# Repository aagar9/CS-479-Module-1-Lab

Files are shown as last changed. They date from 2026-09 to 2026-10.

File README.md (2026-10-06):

# CS 479 – Group 6

This repository is the master repository for **Group 6** in **CS 479 – Wearable Technology Laboratory**.

It will contain the code, documentation, hardware files, and other materials developed for each lab throughout the course.

## Repository Structure

Each lab is organized into its own folder:

- `lab1/` – Lab 1 files and documentation
- `lab2/` – Lab 2 files and documentation

Additional lab folders will be added as the course progresses.

## Group

**Group 6**

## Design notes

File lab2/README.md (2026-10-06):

# BME/CS 479 – Lab 2

## Heart Rate and Breathing Rate Wearable

## Overview

The goal of Lab 2 is to develop a wearable chest strap capable of monitoring a user's heart rate and respiratory rate.

The system uses an AD8232 heart monitor to collect an ECG signal and a Force Sensitive Resistor (FSR) to measure changes associated with inhalation and exhalation.

The collected signals will be processed and displayed through a Processing-based user interface.

---

## Hardware

The Lab 2 wearable uses:

- FireBeetle Board-328P with BLE 4.1
- Micro USB Interface Cable
- Rechargeable Lithium Battery
- FireBeetle Proto Board
- AD8232 Heart Monitor
- ECG Leads
- Snap-On ECG Electrodes
- Force Sensitive Resistor (FSR)
- 10 kOhm Resistor
- Elastic Band
- Tape or Glue
- 3D Printed FSR Backing
- 3D Printed Clasp
- Wire and Wire Wrapping Tool
- Solder and Soldering Iron
- Athletic Tape
- Female Headers

---

## System Design

The wearable collects two primary biosignals:

### ECG

The AD8232 heart monitor records the user's ECG signal.

The ECG signal will be used to calculate and display:

- Heart rate
- Resting heart rate
- Cardio zone
- ECG activity over time

### Respiration

The FSR detects changes caused by expansion and contraction of the chest during inhalation and exhalation.

The respiratory signal will be used to calculate and display:

- Respiratory rate
- Resting respiratory rate
- Inhalation duration
- Exhalation duration
- Respiratory activity over time

---

## User Interface

The user interface is being developed using **Processing (Java Mode)**.

The interface provides three primary operating modes:

1. Fitness Mode
2. Stress Monitoring Mode
3. Meditation Mode

The initial rough Processing UI prototype is located at:

`First_Heart_Breathing_UI/First_Heart_Breathing_UI.pde`

The initial UI currently uses simulated values and placeholder graphs. These will later be replaced with data collected from the wearable sensors.

---

## Fitness Mode

Fitness Mode will begin by collecting a **30-second baseline** from the user.

The baseline will be used to determine:

- Resting heart rate
- Resting respiratory rate

After baseline collection, the interface will display the user's current cardio zone.

Maximum heart rate will be estimated using:

`Maximum Heart Rate = 220 - age`

During physical activity, the interface will monitor the user's ECG and respiratory signals.

The interface will display:

- Current heart rate
- Current respiratory rate
- Cardio zone
- ECG activity
- Cardio-zone activity
- Respiratory activity
- Inhalation duration
- Exhalation duration

The activity graph will eventually be color-coded based on the amount of time spent in each cardio zone.

---

## Stress Monitoring Mode

Stress Monitoring Mode will also begin by collecting a **30-second baseline**.

The baseline will be used to determine:

- Resting heart rate
- Resting respiratory rate

The user's heart rate and respiratory rate will then be monitored during different activities.

The interface will compare the collected data with the user's baseline and use the input analysis to determine whether the user is:

- Calm
- Stressed

The final interface will automatically display the detected state.

---

## Meditation Mode

Meditation Mode will begin by collecting a **30-second baseline**.

The baseline will display:

- Resting heart rate
- Resting respiratory rate

During meditation, the interface will monitor:

- Current heart rate
- Current respiratory rate
- Inhalation duration
- Exhalation duration

The target breathing pattern is:

`Inhalation Period = 1/3 of Exhalation Period`

The interface will continually determine whether the user is maintaining this breathing pattern.

If the breathing criterion is not met for **three consecutive breaths**, an indicator will be activated on the interface.

---

## Required Interface Graphs

The final interface must display all three required graphs:

1. ECG
2. Cardio Zone
3. Respiratory Signal

The respiratory portion of the interface will also display:

- Respiratory rate
- Inhalation duration
- Exhalation duration

---

## Signal Processing

The ECG and respiratory signals may require signal processing to reduce noise and improve the accuracy of the calculated measurements.

Future development may include:

- Signal filtering
- Peak detection
- Heartbeat detection
- Breath detection
- Baseline calculation
- Heart-rate calculation
- Respiratory-rate calculation
- Inhalation and exhalation detection

---

## Current Progress

### Completed

- Repository reorganized into separate `lab1` and `lab2` folders
- Processing development environment configured
- Initial Processing UI created
- Fitness Mode button implemented
- Stress Monitoring Mode button implemented
- Meditation Mode button implemented
- Mode switching implemented
- Initial heart-rate display implemented using placeholder data
- Initial respiratory-rate display implemented using placeholder data
- Initial ECG graph implemented using simulated data
- Initial cardio-zone display implemented
- Initial respiratory graph implemented using simulated data
- Initial Stress Mode screen implemented
- Initial Meditation Mode screen implemented

### In Progress

- 30-second baseline collection
- FireBeetle integration
- AD8232 ECG sensor integration
- FSR respiratory sensor integration
- Live sensor communication with Processing
- ECG signal processing
- Heart-rate calculation
- Respiratory-rate calculation
- Inhalation and exhalation detection
- Cardio-zone calculation
- Cardio-zone activity graph
- Stress/calm classification
- Meditation breathing-pattern detection
- Three-consecutive-breath warning indicator

---

## Project Structure

```text
lab2/
├── README.md
└── First_Heart_Breathing_UI/
    └── First_Heart_Breathing_UI.pde

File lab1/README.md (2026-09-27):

# PPG Wearable – Fitness and Calm/Stress Monitoring

This repository contains the software developed for the PPG module of the Wearables and Nearables Technology Laboratory.

The project implements two main applications:

- **Task I – Fitness Mode**
- **Task II – Calm / Stress Detection**

An additional version of Task I also includes an **estimated calorie expenditure feature**.

---

## System Architecture

The wearable uses a peripheral/central BLE architecture:

MAX30101 / MAX32664  
→ Peripheral FireBeetle  
→ BLE  
→ Central FireBeetle  
→ USB / Serial  
→ Processing

The **peripheral FireBeetle** is connected to the PPG sensor and runs the Arduino firmware.

The **central FireBeetle** is connected to the computer and acts as a BLE-to-USB bridge.

The MAX32664 biometric hub performs the low-level PPG processing and provides already processed values such as:

- Heart rate
- SpO2
- Confidence
- Sensor status

The Processing applications therefore perform the higher-level logic, including signal validation, baseline acquisition, classification, graphing, and user-interface control.

---

# Repository Files

## `ppg1`

Processing application implementing **Task I – Fitness Mode**.

Before starting the task, the program checks whether the PPG signal has been reliably acquired using a rolling window containing the latest 10 HR samples.

A sample is considered valid when:

- `HR > 0`

The signal is accepted when:

- at least **7 of the latest 10 samples are valid**
- the most recent sample is also valid

After signal acquisition, a **30-second resting baseline** is recorded.

Resting HR is calculated as the mean of the valid HR samples acquired during this phase.

Signal quality is calculated as:

`valid samples / total received samples`

If baseline quality is below **70%**, the acquisition must be repeated.

### Fitness Mode

The estimated maximum heart rate is calculated as:

`HRmax = 220 - age`

Each valid HR measurement is expressed as a percentage of HRmax and assigned to the corresponding exercise-intensity zone.

The interface displays:

- Current HR
- Resting HR
- Average HR
- Beat interval
- SpO2
- Confidence
- Current cardio zone
- Activity time
- Classified time
- Signal quality
- Time spent in each cardio zone

The HR graph is color-coded according to the cardio zone.

When `HR = 0`, the sample is treated as missing data and is excluded from:

- HR averages
- cardio-zone classification
- zone-time accumulation
- graph points

This creates a graph gap instead of displaying an artificial HR value.

After pressing **STOP**, the complete session remains visible for review.

---

## `ppg_fitness_calories_no_age_limit`

Extended version of `ppg1`.

It implements the same **Fitness Mode**, while also estimating **energy expenditure and calories burned**.

The calorie calculation uses:

- Heart rate
- Age
- Sex
- Body mass

Energy expenditure is estimated from HR using sex-specific equations and is integrated over time.

Calorie integration is performed only during valid HR intervals.

If signal loss occurs, the integration is interrupted instead of estimating calories across missing data.

The interface additionally displays:

- Estimated calories

This feature is an additional project implementation and is not required for the basic Fitness Mode.

---

## `ppg2`

Processing application implementing **Task II – Calm / Stress Detection**.

The initial signal acquisition and 30-second resting baseline use the same logic as Task I.

The Task II workflow is:

Resting baseline  
→ Calm calibration  
→ Stress calibration  
→ Live detection

### Calm Calibration

During Calm calibration, HR is recorded while the user attempts to relax.

A **time-weighted mean HR** is calculated, giving slightly greater importance to the later samples of the calibration.

The calibration is accepted only if HR decreases by at least **1 bpm** relative to resting HR.

### Stress Calibration

During Stress calibration, HR is recorded while the user performs the stress task.

The Stress calibration must last at least **60 seconds**.

The same time-weighted averaging method is used.

The calibration is accepted only if HR increases by at least **1 bpm** relative to resting HR.

If a new calibration is too weak, the previously accepted calibration is retained.

### Live Detection

During live detection, the latest **10 HR samples** are stored in a rolling window.

If at least **7 of the 10 samples are valid**, a smoothed HR is calculated from the valid values.

The smoothed HR is compared with personalized Calm and Stress thresholds obtained from the calibration phase.

The possible detected states are:

- `CALM`
- `NEUTRAL`
- `STRESSED`

A **2-second persistence requirement** is used before confirming a state transition.

This prevents brief threshold crossings from being interpreted as real state changes.

The algorithm also uses **hysteresis**, with different entry and exit thresholds, to avoid repeated switching when HR oscillates near a decision boundary.

When a transition to `STRESSED` is confirmed, Processing sends the command:

`'B'`

to the wearable, which triggers two buzzer tones.

The Task II interface displays:

- Current HR
- Smoothed HR
- Resting HR
- Beat interval
- SpO2
- Confidence
- Calm threshold
- Stress threshold
- Current detected state
- Signal quality
- Detection time
- Measured and smoothed HR curves

---

# Arduino Firmware

## `arduino_sensor`

Arduino firmware used for **Task I**.

The peripheral FireBeetle communicates with the MAX32664 biometric hub and reads the processed biometric outputs.

The firmware transmits:

- Heart rate
- Confidence
- SpO2
- Status

The data flow is:

PPG sensor  
→ Peripheral FireBeetle  
→ BLE  
→ Central FireBeetle  
→ USB  
→ Processing

The Processing applications `ppg1` and `ppg_fitness_calories_no_age_limit` read these data and perform the application-level processing.

---

## `arduino_sensor_buzzer`

Arduino firmware used for **Task II**.

It performs the same sensor acquisition and transmission as `arduino_sensor`, but it also receives the buzzer command from Processing.

When the peripheral receives:

`'B'`

the buzzer produces two tones.

The feedback path is:

Processing detects `STRESSED`  
→ sends `'B'`  
→ Central FireBeetle  
→ BLE  
→ Peripheral FireBeetle  
→ buzzer sounds twice

---

# Processing Program Structure

The Processing applications use an event-driven structure.

## `setup()`

Runs once when the program starts.

It initializes:

- the graphical interface
- serial communication
- colors and layout variables
- program variables

## `draw()`

Runs continuously.

It is mainly responsible for:

- drawing the current interface screen
- updating graphical elements
- checking time-based transitions

Sensor sample counters are not updated inside `draw()`.

## `serialEvent()`

Runs whenever a complete sensor record is received.

It:

1. Reads the serial data.
2. Extracts HR, SpO2 and confidence.
3. Determines whether the HR sample is valid.
4. Records the sample time.
5. Sends the sample to the correct algorithm according to the current program state.

For example:

- `WAITING_SIGNAL` → update the 10-sample validity window
- `BASELINE` → process the resting-baseline sample
- `FITNESS_ACTIVE` → process the Fitness sample
- `CALM_ACTIVE / STRESS_ACTIVE` → process the calibration sample
- `DETECTION_ACTIVE` → update the live-detection algorithm

## `mousePressed()`

Runs only when the user clicks.

It handles actions such as:

- START
- STOP
- Retry
- Calm Calibration
- Stress Calibration
- Start Detection

---

# Data Quality Strategy

The software includes several checks to manage temporary PPG signal loss.

| Stage | Strategy |
|---|---|
| Initial acquisition | At least 7 valid samples among the latest 10 |
| Latest sample | Must also be valid |
| Resting baseline | 30-second acquisition |
| Baseline acceptance | At least 70% valid samples |
| Invalid HR | HR = 0 treated as missing data |
| Fitness graph | Missing samples shown as gaps |
| Task II | 10-sample rolling mean |
| State transition | 2-second persistence |
| State stability | Hysteresis with different entry/exit thresholds |

---

# Beat Interval

The beat interval displayed by the interface is estimated from the current HR as:

`Beat interval [ms] = 60000 / HR`

It is therefore an HR-derived estimate rather than a direct beat-to-beat measurement extracted from individual PPG peaks.

---

# How to Run

1. Pair the peripheral and central FireBeetle boards.
2. Upload the appropriate Arduino firmware to the peripheral board:
   - `arduino_sensor` for Task I
   - `arduino_sensor_buzzer` for Task II
3. Connect the central FireBeetle to the PC through USB.
4. Close the Arduino Serial Monitor.
5. Open the corresponding Processing application:
   - `ppg1`
   - `ppg_fitness_calories_no_age_limit`
   - `ppg2`
6. Select the correct serial port if necessary.
7. Position the PPG sensor correctly.
8. Wait for stable signal acquisition.
9. Follow the instructions shown in the Processing interface.

---

# File Summary

| File | Platform | Function |
|---|---|---|
| `ppg1` | Processing | Task I – Fitness Mode |
| `ppg_fitness_calories_no_age_limit` | Processing | Task I + calorie estimation |
| `ppg2` | Processing | Task II – Calm / Stress Detection |
| `arduino_sensor` | Arduino | PPG acquisition and transmission for Task I |
| `arduino_sensor_buzzer` | Arduino | PPG acquisition, transmission, and buzzer feedback for Task II |

---

## Notes

The MAX32664 performs the low-level PPG filtering and biometric processing.

The custom Processing software implements the application-level algorithms developed for this project, including:

- signal validation
- resting-HR estimation
- cardio-zone classification
- personalized Calm/Stress calibration
- temporal smoothing
- persistence
- hysteresis
- graphical visualization
- buzzer feedback

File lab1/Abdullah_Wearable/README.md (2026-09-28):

# Wearable PPG Monitor — BME/CS 479

Arduino firmware and a single-file Processing interface for the wearable heart-rate and blood-oxygen lab project.

## Files

- `WearableLabComplete/WearableLabComplete.pde`: Processing application. Open this file in Processing; keep its enclosing folder name unchanged.
- `WearableLabSensor/WearableLabSensor.ino`: firmware for the wearable FireBeetle carrying BOTH the PPG sensor and buzzer.

No separate Java source files, verification tools, recordings, or exported participant data are needed to run the application.

## Hardware and wiring

Two already-paired DFRobot FireBeetle 328P BLE 4.1 boards, a SparkFun MAX30101/MAX32664 sensor board, and a buzzer. This setup assumes the existing BLE pairing and transport configuration; these sketches do not establish pairing.

| Wearable FireBeetle | Sensor board |
| --- | --- |
| 3V3 | 3V3 |
| GND | GND |
| SDA | SDA |
| SCL | SCL |
| D4 | RST |
| D5 | MFIO |

Buzzer positive connects to D12; negative connects to GND. The USB-connected FireBeetle has no external sensor or buzzer.

## Run Processing

1. Install Processing 4 (developed with 4.5.6). Its desktop distribution includes a Java runtime; no separate Java installation is needed.
2. Ensure the Processing Serial library is available (`processing.serial`).
3. Copy the entire `WearableLabComplete` folder and open its `.pde` file.
4. Connect the empty bridge board by USB and power the paired wearable board.
5. Close Arduino Serial Monitor and other applications using the serial port.
6. Run the sketch and select the bridge's actual port on the setup screen. COM3 is only the original computer's default. Communication uses 115200 baud.
7. Check live readings and use Test buzzer. Enter the wearer's age and record a new resting baseline and calibrations.

If the boards already have the correct firmware, uploading Arduino code again is unnecessary.

## Upload Arduino firmware

Install Arduino IDE, the board support for your FireBeetle, and **SparkFun Bio Sensor Hub Library** through Library Manager. `Wire` comes with the Arduino core. Use the board configuration previously confirmed for the physical FireBeetle 328P, which runs at 3.3 V / 8 MHz.

1. Stop Processing and close Serial Monitor.
2. Disconnect/power off the computer-side FireBeetle. Connect the sensor-and-buzzer board directly by USB and upload `WearableLabSensor` to it.
3. Restore normal power and the existing paired wireless arrangement, then run Processing.

Keep only the intended target powered during the upload: the paired FireBeetle link supports wireless programming. The computer-side board is already configured and needs no sketch from this package.

## Application behavior

- Heart rate, oxygen saturation, confidence, and signal-quality display.
- 30-second resting baseline.
- Fitness mode with colored heart-rate zones, recovery graph, and time in each zone.
- Calm calibration lasting at least 30 seconds and stress calibration lasting 60 seconds.
- Monitoring uses smoothed heart rate and requires a sustained threshold crossing for 2 seconds before entering STRESSED. Entry triggers two beeps; it does not continuously repeat while remaining STRESSED.
- Test buzzer sends the same command path and displays board acknowledgments.
- Raw PPG pulse-interval detection; legacy heart-rate-only data uses a clearly labeled estimated interval.
- Optional CSV export. Generated exports are ignored by Git.

If calibration has sufficient valid data but does not produce the expected heart-rate change, the interface labels its fallback thresholds as defaults. Stress labels are heart-rate-based classifications, not confirmation of a person's emotional state.

## Signal failures and validation

Firmware checks sensor replies, rejects incomplete samples, and attempts sensor reinitialization after failures. Processing clears stale readings on sensor faults. Persistent FIFO errors still require checking sensor power and connections.

Before packaging, the source version was compiled for AVR ATmega328P 3.3 V / 8 MHz (Arduino AVR core 1.8.6), and the Processing version passed 36 behavior checks. This package preserves those source files unchanged. Physical fault recovery, long-duration BLE reliability, and operation on another computer have not been verified here.

Raw packets are limited to 25 per second. Pulse intervals therefore have roughly 40 ms sample spacing plus polling jitter; they are not ECG beat-interval measurements.

## Add to the shared GitHub repository

Copy the two sketch folders, this README, and `.gitignore` into the desired project directory of the shared repository. Preserve each sketch's folder and filename. If that repository already has a README or `.gitignore`, merge these contents rather than replacing the existing files.

Review and commit the files through your usual GitHub workflow. Do not upload the ZIP itself as a substitute for the source folders. No license is assigned by this package; the team can choose one if needed.

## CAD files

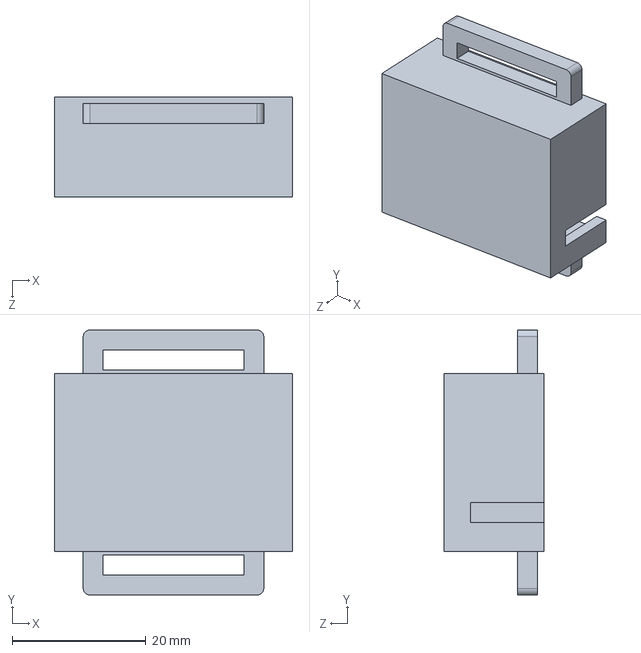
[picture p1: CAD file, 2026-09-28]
lab1/Abdullah_Wearable/PPG_Cover_Strap_v8.SLDPRT
35.6 x 39.6 x 15.0 mm

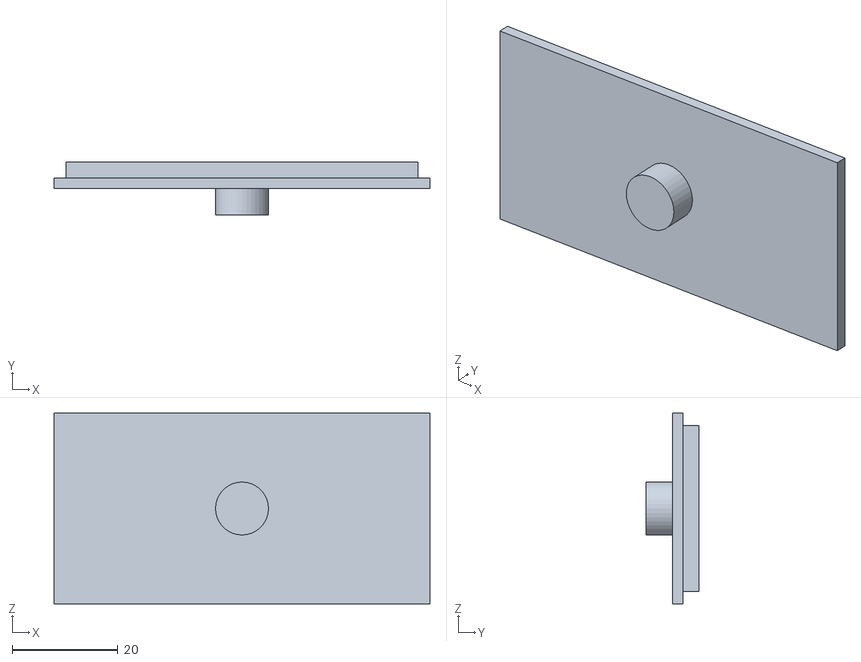
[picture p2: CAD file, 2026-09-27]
lab1/box_cap.STL
71.0 x 10.0 x 36.0

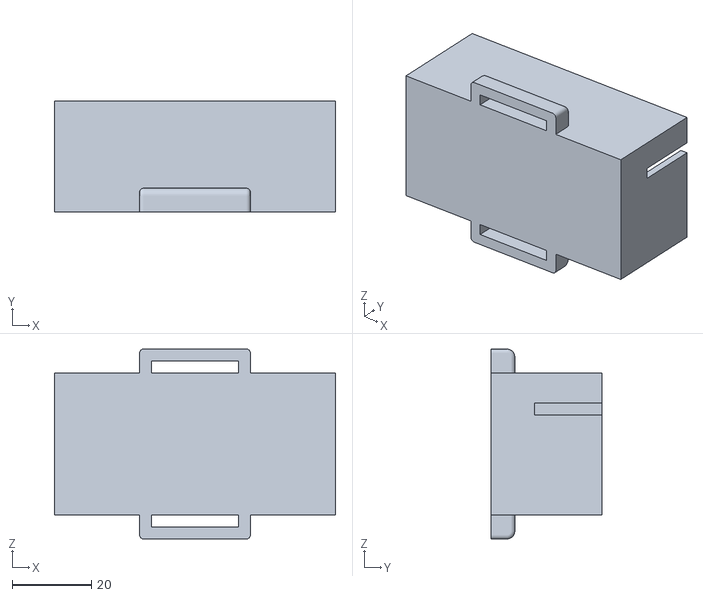
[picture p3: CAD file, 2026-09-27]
lab1/Box.STL
71.0 x 28.0 x 48.0

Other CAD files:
lab1/lid.SLDPRT
lab1/Abdullah_Wearable/PPG_Cover_Strap_v8.stl

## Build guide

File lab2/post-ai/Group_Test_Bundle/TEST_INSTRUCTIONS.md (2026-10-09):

# Group testing package (post-AI)

## Test these exact files

1. **Arduino IDE:** `Group_Test_Arduino/Group_Test_Arduino.ino`
2. **Processing IDE:** `Group_Test_Bundle/Group_Test_Bundle.pde`

The Processing sketch contains these original tabs, unchanged in logic:
- Heart_Breathing_Integrated.pde
- FitnessMode.pde
- MeditationMode.pde
- SignalProcessing.pde
- StressMode.pde

Firmware copied from: `lab2/pre-ai/First_Heart_Breathing_UI/arduino_Lab02.ino`

## Test order
1. Close Processing and the Arduino Serial Monitor before changing which app uses the serial port.
2. Upload the Arduino sketch to the FireBeetle using the correct board and port.
3. Open the single Processing `.pde` file. Confirm the serial port and baud rate match the board (the current UI may have a hardcoded `COM3`).
4. Verify live ECG and respiration data, HR/RR and inhale/exhale times.
5. Fitness: baseline, activity selection, all five animations (especially stairs), cardio zones, graphs, end/results.
6. Stress: all three 30-second calibration phases, monitoring status and graphs.
7. Meditation: baseline, 1:3 breathing target, alert after three consecutive missed breaths.
8. Test on Windows and macOS if available; record screenshots and Processing console errors.

**Important:** Combining files does not guarantee compilation or hardware compatibility. Test with the actual board. Do not open the original multi-tab sketch at the same time when checking this bundle.

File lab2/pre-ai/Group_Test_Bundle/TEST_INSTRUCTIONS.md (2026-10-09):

# Pre-AI group testing package

## Exact files to open
- **Processing:** `Pre_AI_Group_Test/Pre_AI_Group_Test.pde`
- **Arduino IDE:** `Pre_AI_Arduino/Pre_AI_Arduino.ino`

## Testing checklist
1. Select the correct FireBeetle board and port in Arduino IDE. Verify, then upload firmware.
2. Close Arduino Serial Monitor before starting Processing (only one app can own the port).
3. Open the Processing `.pde` and press Run. Confirm it compiles.
4. Confirm serial port connects and ECG and FSR graphs receive live samples.
5. Test ECG lead removal and reconnection; Arduino sends `!,FSR` when leads are off.
6. Test Home, Fitness, Stress and Meditation buttons and 30-second baseline behavior.
7. Record screenshots, actual HR/RR readings, and any compilation or serial errors.

## Notes
The Processing source is consolidated from the three existing pre-AI tabs.
The additional `Hearth_breathing_integrated.pde` is deliberately excluded because it is a separate overlapping sketch.
The firmware is copied from `arduino_Lab02.ino`.
The bundle is not hardware-validated by this script.

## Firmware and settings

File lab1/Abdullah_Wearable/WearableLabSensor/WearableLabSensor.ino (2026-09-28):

#include <Wire.h>
#include <SparkFun_Bio_Sensor_Hub_Library.h>

// FireBeetle 328P BLE 4.1: preserve the lab's wiring.
const uint8_t RESET_PIN=4, MFIO_PIN=5, BUZZER_PIN=12, HUB_ADDRESS=0x55;
SparkFun_Bio_Sensor_Hub bioHub(RESET_PIN, MFIO_PIN);
bool sensorReady=false;
uint8_t beepPhase=0;
unsigned long beepStarted=0, lastPoll=0;
uint8_t readFailureStage=0, readFailureCode=0;
unsigned long lastErrorReport=0;
bool errorReported=false;
unsigned long lastRecoveryAttempt=0, lastTransmit=0, lastGoodSample=0;
uint8_t recoveryAttempts=0, consecutiveCountErrors=0;
const unsigned long TRANSMIT_INTERVAL_MS=40; // At most 25 raw packets/s over BLE.

// Execute a hub read with explicit I2C/status/length checks. MODE_ONE sensor +
// algorithm output is 18 payload bytes, fitting the AVR Wire 32-byte buffer.
bool hubRead(uint8_t family,uint8_t index,uint8_t *data,uint8_t count) {
  readFailureStage=0; readFailureCode=0;
  Wire.beginTransmission(HUB_ADDRESS); Wire.write(family); Wire.write(index);
  uint8_t busResult=Wire.endTransmission();
  if(busResult!=0) { readFailureStage=1; readFailureCode=busResult; return false; }
  delay(2); // Required hub command response delay, not a sampling-rate delay.
  uint8_t got=Wire.requestFrom(HUB_ADDRESS,(uint8_t)(count+1));
  if(got!=count+1) {
    readFailureStage=2; readFailureCode=got;
    while(Wire.available()) Wire.read(); return false;
  }
  uint8_t status=Wire.read();
  for(uint8_t i=0;i<count;i++) data[i]=Wire.read();
  if(status!=0) { readFailureStage=3; readFailureCode=status; return false; }
  return true;
}

// Report the actual failure once per second instead of flooding the serial link.
// I2C write code 2 = address NACK; code 3 = data NACK. A nonzero hub status
// is a sensor command response, distinct from wiring/transport errors.
void reportReadError(bool fifoCount) {
  if(errorReported && millis()-lastErrorReport<1000) return;
  errorReported=true; lastErrorReport=millis();
  Serial.print(fifoCount?F("ERROR FIFO count | "):F("ERROR FIFO sample | "));
  if(readFailureStage==1) Serial.print(F("I2C write code="));
  else if(readFailureStage==2) Serial.print(F("short reply bytes="));
  else Serial.print(F("hub status="));
  Serial.println(readFailureCode);
}

// Decode the unsigned 24-bit optical channel values.
uint32_t value24(const uint8_t *p) { return ((uint32_t)p[0]<<16)|((uint32_t)p[1]<<8)|p[2]; }

// Start only one double-beep sequence at a time; do not block sensor polling.
void checkBuzzer() {
  while(Serial.available()) {
    char command=Serial.read();
    if(command=='B' && beepPhase==0) { beepPhase=1; beepStarted=millis(); tone(BUZZER_PIN,1800); Serial.println(F("BUZZER started")); }
  }
  unsigned long elapsed=millis()-beepStarted;
  if(beepPhase==1 && elapsed>=300) { noTone(BUZZER_PIN); beepPhase=2; beepStarted=millis(); }
  else if(beepPhase==2 && elapsed>=250) { tone(BUZZER_PIN,1800); beepPhase=3; beepStarted=millis(); }
  else if(beepPhase==3 && elapsed>=300) { noTone(BUZZER_PIN); beepPhase=0; Serial.println(F("BUZZER complete")); }
}

// Reinitialize both the I2C peripheral and the sensor after a broken FIFO read.
// Explicit pin arguments restore MFIO to OUTPUT before the reset sequence.
bool initializeSensor() {
  Wire.end(); Wire.begin(); Wire.setClock(100000);
  Wire.setWireTimeout(25000,true); // AVR Wire: bound a stuck bus and reset TWI on timeout.
  Wire.clearWireTimeoutFlag();
  if(bioHub.begin(Wire,RESET_PIN,MFIO_PIN)!=0) { Serial.println(F("ERROR sensor connection")); return false; }
  if(bioHub.configSensorBpm(MODE_ONE)!=0) { Serial.println(F("ERROR sensor configuration")); return false; }
  if(bioHub.agcAlgoControl(ENABLE)!=0) { Serial.println(F("ERROR automatic gain configuration")); return false; }
  sensorReady=true;
  consecutiveCountErrors=0; lastGoodSample=millis(); lastPoll=millis();
  lastTransmit=millis();
  Serial.println(F("READY raw PPG; BPM; confidence; SpO2; status"));
  return true;
}

// Discard partial frames. Never retry a partially consumed FIFO packet as new data.
void scheduleRecovery() {
  sensorReady=false;
  lastRecoveryAttempt=millis();
  Serial.println(F("ERROR sensor recovering; waiting to reset connection"));
}

// Retry automatically with backoff. Finish any active beep before a blocking reset.
void recoverSensor() {
  unsigned long waitMs=recoveryAttempts<3?1000:10000;
  if(beepPhase!=0 || millis()-lastRecoveryAttempt<waitMs) return;
  if(recoveryAttempts<255) recoveryAttempts++;
  Serial.println(F("ERROR sensor recovering; resetting sensor now"));
  initializeSensor();
  lastRecoveryAttempt=millis();
}

// Configure raw output only on the wireless board carrying the physical sensor.
void setup() {
  Serial.begin(115200); pinMode(BUZZER_PIN,OUTPUT); noTone(BUZZER_PIN);
  initializeSensor();
  lastRecoveryAttempt=millis();
}

// Read every available sample. Backlogs are excluded from pulse timing because
// their acquisition times are unknown; this avoids timing buffered reads as beats.
void loop() {
  checkBuzzer();
  if(!sensorReady) { recoverSensor(); return; }
  if(millis()-lastPoll<2) return;
  unsigned long pollTime=millis();
  bool promptPoll=(pollTime-lastPoll<=10);
  lastPoll=pollTime;
  uint8_t count=0;
  if(!hubRead(0x12,0x00,&count,1)) {
    reportReadError(true);
    if(++consecutiveCountErrors>=3) { consecutiveCountErrors=0; scheduleRecovery(); }
    return;
  }
  consecutiveCountErrors=0;
  if(count==0) {
    if(millis()-lastGoodSample>5000) {
      Serial.println(F("ERROR sensor stopped producing samples")); scheduleRecovery();
    }
    return;
  }
  bool timingUsable=(count==1 && promptPoll);
  for(uint8_t i=0;i<count;i++) {
    checkBuzzer(); uint8_t data[18];
    unsigned long timestamp=millis();
    if(!hubRead(0x12,0x01,data,18)) { reportReadError(false); scheduleRecovery(); return; }
    lastGoodSample=millis();
    if(millis()-lastRecoveryAttempt>30000) recoveryAttempts=0;
    // Drain every sensor sample, but transmit only the most recent sample of a
    // batch and cap the BLE traffic. Sending every 100 Hz text frame overloads
    // the board's nominal 4 KB/s wireless link. Missing timing stays flagged.
    if(i+1<count || timestamp-lastTransmit<TRANSMIT_INTERVAL_MS) continue;
    lastTransmit=timestamp;
    uint16_t hr=((uint16_t)data[12]<<8)|data[13];
    uint16_t spo2=((uint16_t)data[15]<<8)|data[16];
    // PPG,board_ms,IR,red,HR_bpm,confidence,SpO2,status,timing_usable
    Serial.print(F("PPG,")); Serial.print(timestamp); Serial.print(',');
    Serial.print(value24(data)); Serial.print(','); Serial.print(value24(data+3)); Serial.print(',');
    Serial.print(hr/10.0,1); Serial.print(','); Serial.print(data[14]); Serial.print(',');
    Serial.print(spo2/10.0,1); Serial.print(','); Serial.print(data[17]); Serial.print(',');
    Serial.println(timingUsable?1:0);
  }
}

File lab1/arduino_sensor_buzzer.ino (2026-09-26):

#include <Wire.h>
#include <SparkFun_Bio_Sensor_Hub_Library.h>


// ============================================================
// SENSOR
// ============================================================

int resPin = 4;
int mfioPin = 5;

SparkFun_Bio_Sensor_Hub bioHub(
  resPin,
  mfioPin
);

bioData body;


// ============================================================
// BUZZER
// ============================================================

const int BUZZER_PIN = 12;


// ============================================================
// SETUP
// ============================================================

void setup()
{
  Serial.begin(115200);

  Wire.begin();


  // ----------------------------------------------------------
  // Buzzer
  // ----------------------------------------------------------

  pinMode(
    BUZZER_PIN,
    OUTPUT
  );

  noTone(
    BUZZER_PIN
  );


  // ----------------------------------------------------------
  // PPG sensor
  // ----------------------------------------------------------

  int result =
    bioHub.begin();


  if (result == 0)
  {
    Serial.println(
      "Sensor started!"
    );
  }

  else
  {
    Serial.println(
      "Could not communicate with the sensor!"
    );
  }


  Serial.println(
    "Configuring Sensor...."
  );


  int error =
    bioHub.configBpm(
      MODE_ONE
    );


  if (error == 0)
  {
    Serial.println(
      "Sensor configured."
    );
  }

  else
  {
    Serial.println(
      "Error configuring sensor."
    );
  }


  delay(4000);


  Serial.println(
    "Loading up the buffer with data...."
  );
}


// ============================================================
// MAIN LOOP
// ============================================================

void loop()
{
  // ----------------------------------------------------------
  // 1. Check commands received from Processing
  // ----------------------------------------------------------

  checkBuzzerCommand();


  // ----------------------------------------------------------
  // 2. Read PPG sensor
  // ----------------------------------------------------------

  body =
    bioHub.readBpm();


  // ----------------------------------------------------------
  // 3. Send sensor data to Processing
  // ----------------------------------------------------------

  Serial.print(
    "Heartrate: "
  );

  Serial.print(
    body.heartRate
  );

  Serial.print(
    " bpm | "
  );


  Serial.print(
    "Confidence: "
  );

  Serial.print(
    body.confidence
  );

  Serial.print(
    " % | "
  );


  Serial.print(
    "Oxygen: "
  );

  Serial.print(
    body.oxygen
  );

  Serial.print(
    " % | "
  );


  Serial.print(
    "Status: "
  );

  Serial.println(
    body.status
  );


  delay(500);
}


// ============================================================
// RECEIVE BUZZER COMMAND
// ============================================================

void checkBuzzerCommand()
{
  if (
    Serial.available() > 0
  )
  {
    char command =
      Serial.read();


    if (
      command == 'B'
    )
    {
      beepTwice();
    }
  }
}


// ============================================================
// DOUBLE BEEP
// ============================================================

void beepTwice()
{
  // First beep

  tone(
    BUZZER_PIN,
    1800
  );

  delay(300);

  noTone(
    BUZZER_PIN
  );


  // Pause

  delay(250);


  // Second beep

  tone(
    BUZZER_PIN,
    1800
  );

  delay(300);

  noTone(
    BUZZER_PIN
  );
}

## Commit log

2026-09-26 Add Arduino sensor buzzer code
    [arduino_sensor_buzzer.ino]
2026-09-28 Add combined Processing app and Arduino sensor code
2026-09-28 Add SolidWorks PPG cover with strap model
    [PPG_Cover_Strap_v8.SLDPRT]
2026-09-28 Add printable STL for PPG cover with strap
    [PPG_Cover_Strap_v8.stl]
2026-10-06 Organize Lab 1 and add initial Lab 2 Processing UI
    [Box.STL, PPG_Cover_Strap_v8.SLDPRT, PPG_Cover_Strap_v8.stl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]
2026-10-06 Move Arduino file into lab2
2026-10-08 Fix ECG graph scaling and boundaries across all modes
    [FitnessMode.pde, Heart_Breathing_Integrated.pde, MeditationMode.pde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]
2026-10-08 Update stress detection and fix meditation label overlap
    [MeditationMode.pde, StressMode.pde]
2026-10-08 Add activity-specific fitness animations and personalized stress calibration
2026-10-08 Add manual acquisition buttons for stress calibration
2026-10-08 Add live sensor data to pre-AI Processing UI
2026-10-09 Improve post-AI dashboard and fix fitness activity animations
    [FitnessMode.pde, Heart_Breathing_Integrated.pde]
2026-10-09 Add consolidated Processing and Arduino group test bundle
2026-10-13 Create Lab 3 directory for Arduino and Processing
2026-10-13 Add Lab 3 Arduino and Processing files
2026-10-26 Remove outdated Lab 3 Arduino and Processing directories
2026-10-26 Organize first device files and correct Rehab filename
2026-10-26 Add second device Smart Tattoo Piano Arduino and Processing code
2026-10-26 Move second device enclosure files into dedicated folder
